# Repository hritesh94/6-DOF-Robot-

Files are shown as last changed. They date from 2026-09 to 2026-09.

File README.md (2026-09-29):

# TW2KA 6-DOF Robot Arm — custom PCB, firmware and browser controller 
# Instagram-https://www.instagram.com/zerobudgetbuilds?stkn=Z2p6NzZ4MDZwZGZy&utm_source=ig_contact_invite
# Youtube-https://youtube.com/@zerobudgetbuilds-e4w?si=uFIiYkhq8qUiVjJG

WhatsApp Image 2026-09-28 at 2 36 28 PM


## Here if you see closely the tx and rx connection to the Teensy board is wrong it should be flipped i will correct and upload it in the next iteration
pcb

A 3D-printed 6-axis robot arm that homes itself, moves in joint or Cartesian space using inverse kinematics, and **draws** from G-code, SVG files or photos.

> 📹 

https://github.com/user-attachments/assets/a5f0eb35-01ec-4ff1-84e9-ad130a259d0c

## Final Result of What the Robot drew
WhatsApp Image 2026-09-27 at 4 41 34 PM

| | |
|---|---|
| **Mechanics** | Open-source [TW2KA](https://youtube.com/@tw2ka644) arm, 3D-printed on my own printer, assembled and modified |
| **Electronics** | Custom PCB (KiCad): Teensy 4.1 + 6× TMC2209 stepper drivers + 5 endstops |
| **Firmware** | Arduino/Teensyduino, AccelStepper, coordinated moves, homing, EEPROM calibration |
| **Controller** | Single HTML file: live 3D model (three.js), jogging, Cartesian IK, G-code drawing, image → G-code |
| **Status** | Version 1: working and drawing |

---

## What it can do

- **Jog** each joint (press and hold) and **home** J1–J5 on their endstops
- **Cartesian control**: move the tool in X/Y/Z/roll/pitch/yaw, or position-only with the wrist held still
- **Live 3D model** showing the commanded pose and the real motor position side by side
- **Calibrate from the app**: motor direction, homing direction, zero offset, soft limits and steps/degree per joint, all saved on the Teensy
- **Draw**: run G-code (G0/G1/G2/G3, M3/M5), find the reachable drawing area, fit drawings to it, and convert SVG / PNG / JPG images into G-code (outline or hatch)
- **Safety**: E-stop, endstop protection during moves, per-joint speed caps, table-height limit, wrist-flip blocking

## Repository layout

```
6-DOF-Robot-/
├── README.md                          ← you are here
├── LICENSE
├── app/
│   ├── README.md                      ← what the controller does, how to use it
│   ├── tw2k_controller.html           ← the whole controller (open in Chrome/Edge)
│   └── images/                        ← screenshots of the app
├── firmware/
│   └── tw2k_firmware/
│       └── tw2k_firmware.ino          ← Teensy 4.1 firmware
├── hardware/
│   ├── BOM.md                         ← motors, drives, electronics
│   ├── cad/
│   │   ├── README.md                  ← my parts and changes explained
│   │   ├── pen_holder.3mf             ← my pen holder (print-ready)
│   │   ├── pen_holder_preview.png
│   │   ├── Baseplate-v2.3mf           ← modified TW2KA baseplate (inner circle +2 mm)
│   │   ├── baseplate_v2_preview.png
│   │   ├── base_stand_gear_with_lip.3mf  ← modified TW2KA base gear (added lip)
│   │   ├── base_stand_gear_preview.png
│   │   └── Arduino robot arm files + step/   ← original TW2KA design files (credit: TW2KA)
│   │       ├── README.md
│   │       ├── Arm1/  Arm2/  Base/    ← printable parts
│   │       ├── Assembly step.STEP     ← full 3D assembly
│   │       ├── Hardware.txt           ← original hardware list
│   │       └── coupler stl file for planetary geared nema motor.3mf
│   └── pcb/
│       ├── README.md
│       ├── tw2ka_pcb.kicad_pro        ← open this in KiCad
│       ├── tw2ka_pcb.kicad_sch        ← schematic
│       ├── tw2ka_pcb.kicad_pcb        ← 4-layer board layout
│       ├── fp-lib-table
│       ├── 3d/
│       │   └── tw2ka_pcb.step         ← 3D model of the board
│       └── fabrication/               ← drill files (+ Gerbers)
├── docs/
│   ├── 01-build-log.md                ← the story: what I tried, what failed, why each feature exists
│   ├── 02-hardware.md                 ← PCB, pin map, drivers, motors
│   ├── 03-kinematics.md               ← DH parameters, workspace, how the IK works
│   ├── 04-firmware.md                 ← serial protocol, config, EEPROM
│   ├── 05-controller-app.md           ← code map of the HTML app, how to add features
│   ├── 06-calibration.md              ← first-time setup, step by step
│   ├── 07-drawing.md                  ← G-code and image drawing
│   ├── 08-troubleshooting.md          ← problems I hit and how I fixed them
│   └── roadmap.md                     ← ROS 2, MoveIt, camera, learning plans
└── media/                             ← photos and videos
```

## Quick start

1. **Flash the firmware**: open `firmware/tw2k_firmware/tw2k_firmware.ino` in the Arduino IDE with Teensyduino, board **Teensy 4.1**, USB type **Serial**, install **AccelStepper**, upload.
2. **Open the app**: double-click `app/tw2k_controller.html` in **Chrome or Edge** on a computer (Web Serial is needed; phones run it as a simulator only).
3. **Connect → Enable all → Home all.**
4. Follow [docs/06-calibration.md](docs/06-calibration.md) once, then try Cartesian mode and drawing.

⚠️ Keep a hand near STOP (or press **Esc**) and your motor power switch, especially the first time.

## The story in short

1. My first arm used servo motors; I wanted something **precise**.
2. Builders like **Aaed Musa** and **Michael Reeves** inspired me, but precise arms often use BLDC motors with FOC drivers, far over my ₹10–20k budget.
3. **[Skyentific](https://youtube.com/@skyentific)** showed me a precise arm can use **stepper motors**, but his belts aren't sold in India.
4. I found **[TW2KA](https://youtube.com/@tw2ka644)**, and **[Matt.xyz++](https://youtube.com/@matt-04)** showed the same arm writing with G-code (and mentioned TMC drivers). I bought a 3D printer and printed every TW2KA part.
5. TW2KA uses an Arduino Mega + RAMPS + A4988. I moved to a **Teensy 4.1 + TMC2209s**. On a perfboard I killed two drivers and a motor (lesson: never unplug a motor while powered), so I learned **KiCad** and designed my own PCB.
6. Software: the **TW2KA GUI** only jogged the joints, and **Chris Annin's AR4 app** didn't move my arm correctly in X even with my DH parameters. So I **made my own app**.
7. Debugging on the real arm: J3 turning the wrong way, J5's steps per degree, wrist flips, J2 wiring. Then it drew its first SVG.

Full version: [docs/01-build-log.md](docs/01-build-log.md).

## How this was built (honest credits)

- **Mechanical design**: the open-source **TW2KA** arm ([YouTube](https://youtube.com/@tw2ka644)). I printed all parts on my own 3D printer, assembled the arm and modified parts in Fusion 360 (2–3 iterations, plus my own pen holder).
- **PCB**: designed by me in KiCad, soldered and brought up by me (after an earlier perfboard version).
- **Kinematics measurements**: I measured the link geometry axis-to-axis in Fusion 360; the DH table came from those measurements.
- **Software**: the firmware, inverse kinematics and controller app were written with **Claude (Anthropic)** as an AI coding partner, from my requirements, and then tested, debugged and calibrated by me on the real robot.
- **Inspiration and learning**:
  - [Skyentific](https://youtube.com/@skyentific) (stepper-driven 6-axis arm)
  - [Matt.xyz++](https://youtube.com/@matt-04) (TW2KA arm drawing with G-code, TMC drivers)
  - Chris Annin's **AR4** robot and software
  - **Aaed Musa** and **Michael Reeves** (robot builders who got me started)
  - **DIY Engineers** and **Electronoobs** on YouTube (how TMC stepper drivers work)
  - [Inverse kinematics basics playlist](https://www.youtube.com/watch?v=MYJIEiz2DKg&list=PLY6RHB0yqJVasji1rwZAGYirD8zW1ipj-)
- **Libraries**: [AccelStepper](https://www.airspayce.com/mikem/arduino/AccelStepper/) by Mike McCauley, [three.js](https://threejs.org/).

## License

The firmware and app in this repository are released under the MIT License (see `LICENSE`). The TW2KA mechanical design belongs to its creator; check their license before redistributing any of their CAD files.

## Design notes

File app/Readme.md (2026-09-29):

# TW2KA Arm Controller (web app)

A complete controller for the 6-axis arm in **one HTML file**. Open it in your browser, plug in the Teensy over USB, and you can jog, home, calibrate, move in X/Y/Z with inverse kinematics, and draw from G-code or images, while a live 3D model shows exactly what the arm is doing.



## Requirements

- **Chrome or Edge on a computer.** The app talks to the Teensy with the Web Serial API, which these browsers support.
- The arm's firmware flashed on the Teensy 4.1: [`firmware/tw2k_firmware/tw2k_firmware.ino`](../firmware/tw2k_firmware/tw2k_firmware.ino)
- Nothing to install. On a phone, or without the Teensy, it runs as a **simulator**.

## Quick start

1. Download `tw2k_controller.html` and double-click it (it opens in your browser).
2. Click **Connect Teensy** and pick the Teensy's port.
3. Press **Enable all**, then **Home all**.
4. Jog with **−/+** or drag the sliders. The 3D model follows the real arm.

⚠️ Keep a hand near **STOP** (or press **Esc**) and the motor power switch, especially the first time.

## Features

### Live 3D view
- **Solid arm** = where you're telling it to go. **Faint arm** = where the motors really are.
- Drag to rotate, scroll or pinch to zoom.
- Built from the arm's real DH parameters, so what you see matches the geometry.

### Joint control
- A slider per joint to go to an exact angle.
- **Press and hold − / +** to jog a joint, like a classic robot GUI.
- **Current pose** readout: tool X/Y/Z, roll/pitch/yaw, and all six joint angles.



### Cartesian control (inverse kinematics)


- Move the tool in **X, Y, Z** and set **roll, pitch, yaw**; the app solves all six joint angles.
- **Hold tool angle** mode (uses all 6 joints) or **Position only** mode (J1–J3 move, the wrist stays still).
- Blocks sudden **wrist flips**, respects joint limits, and has a **table-height limit** so the tool never goes into the table.

### Motors
- **Motor enable**: turn each joint's motor on or off.
- **Motor direction**: reverse a joint whose real motion is opposite to the 3D model.
- **Hardware test**: pulse a motor 1600 steps forward and back to check wiring.


### Homing and calibration


- **Home all** or one joint at a time, with live endstop indicators.
- Set each joint's **homing direction**, **zero position** (*zero here*), **soft limits** (*min/max here*, *endstop only*) and **steps per degree** (*fix from measurement*).
- Everything is saved on the Teensy, so it's remembered after a power-cycle.

### Drawing


- Run **G-code** (G0/G1/G2/G3, M3/M5) with straight-line motion and pause / resume / stop.
- **Find drawing area**: shows the largest area the pen can reach (yellow box in 3D).
- **Fit G-code to area**, and **Image → G-code** for SVG, PNG and JPG (outline or hatch fill).
- **Check path** tests every point first and tells you the exact line that can't be reached.

## How it's built

- Plain HTML, CSS and JavaScript in a single file, with [three.js](https://threejs.org/) (r128) for 3D.
- Forward kinematics from the DH table; inverse kinematics with a damped-least-squares solver.
- Talks to the firmware with simple text commands like `M j1 … j6`, `H`, `J n +1`. The full list is in [docs/04-firmware.md](../docs/04-firmware.md).
- Code map and how to add features: [docs/05-controller-app.md](../docs/05-controller-app.md).

Built with **Claude (Anthropic)** as an AI coding partner, from my requirements, and tested and calibrated on the real arm.

## More docs

- First-time setup: [docs/06-calibration.md](../docs/06-calibration.md)
- Drawing guide: [docs/07-drawing.md](../docs/07-drawing.md)
- Troubleshooting: [docs/08-troubleshooting.md](../docs/08-troubleshooting.md)

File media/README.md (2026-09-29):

# Media

Suggested shots (add them and link from the README and docs):

- `drawing.mp4` / `drawing.gif` — the arm drawing (the most important one)
- `pcb_render.png`, `pcb_soldered.jpg`
- `assembly_*.jpg` — build progress
- `app_3d_view.png` — controller with the 3D model
- `reachable_area.png` — yellow drawing-area box
- `first_drawing.jpg`

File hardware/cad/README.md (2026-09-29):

# CAD

The arm is the open-source **TW2KA** design ([TW2KA on YouTube](https://youtube.com/@tw2ka644)); get the original parts from there.

This folder contains only **my own and modified parts**.

## Pen holder

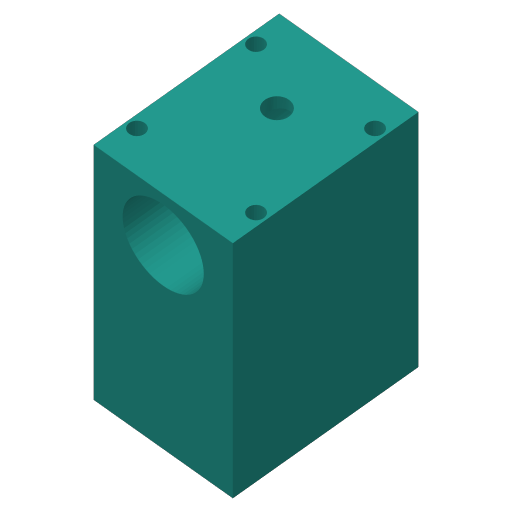
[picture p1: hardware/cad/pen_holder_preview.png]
Pen holder


| | |
|---|---|
| File | [`pen_holder.3mf`](pen_holder.3mf) (print-ready project, opens in Bambu Studio / OrcaSlicer / PrusaSlicer) |
| Size | about 24 × 18 × 33 mm |
| Design | block with four mounting holes plus a centre hole on top (to the J6 flange) and a side bore that holds the pen |
| Why | lets the arm hold a pen for G-code drawing |

After mounting a pen, measure how far the **pen tip is below the flange** and **ahead of it**, and enter both in the controller's G-code drawing card (see [docs/07-drawing.md](../../docs/07-drawing.md)).

## Baseplate v2 (modified TW2KA part)

baseplate_v2_preview

| | |
|---|---|
| File | [`Baseplate-v2.3mf`](Baseplate-v2.3mf) (print-ready project) |
| Size | about 167 × 80 × 12 mm |
| Original | TW2KA baseplate (see [Arduino robot arm files + step](Arduino%20robot%20arm%20files%20+%20step/)) |
| Change | the large inner circle was cut **2 mm** larger |
| Why | [describe what it fixed, e.g. the bearing / shaft now fits without rubbing, and the base turns more smoothly] |

## Base stand gear with lip (modified TW2KA part)

base_stand_gear_preview

| | |
|---|---|
| File | [`base_stand_gear_with_lip.3mf`](base_stand_gear_with_lip.3mf) (print-ready project) |
| Size | about 70 mm across (95 mm including the side arm), 9.3 mm thick |
| Original | TW2KA base stand gear (see [Arduino robot arm files + step](Arduino%20robot%20arm%20files%20+%20step/)) |
| Change | added a **lip** (flange) around the bottom of the toothed pulley |
| Why | [describe what it fixed, e.g. keeps the J1 belt from slipping off the pulley] |

## Other modified parts

- [ ] Parts from my 2–3 Fusion 360 iterations: list each one with what changed and why

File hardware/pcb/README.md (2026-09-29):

# Control PCB (KiCad)

My own control board for the TW2KA arm: a **Teensy 4.1** driving **six TMC2209** stepper drivers, with endstop inputs. Designed in **KiCad 10**.

| | |
|---|---|
| Size | 102 × 100 mm |
| Layers | 4 (F.Cu, In1.Cu, In2.Cu, B.Cu) |
| MCU | Teensy 4.1 (socketed) |
| Drivers | 6 × TMC2209 modules (socketed) |
| Per driver | STEP, DIR, EN to the Teensy; UART RX/TX lines routed (J1–J6_RX/TX); MS1, MS2 and SPREAD selectable |
| Endstops | 5 inputs (SW_1–SW_5) for J1–J5 |
| Power | Motor supply via terminal block and fuse, 100 µF capacitor per driver, separate logic supply (VIO) |
WhatsApp Image 2026-09-28 at 1 49 23 PM
pcb

https://github.com/user-attachments/assets/b51a67fe-33f5-430a-8fab-c27dd11908fc

Pin map and endstop wiring: [docs/02-hardware.md](../../docs/02-hardware.md).

## Files

```
hardware/pcb/
├── tw2ka_pcb.kicad_pro     ← open this in KiCad
├── tw2ka_pcb.kicad_sch     ← schematic
├── tw2ka_pcb.kicad_pcb     ← board layout
├── fp-lib-table            ← project footprint library table
├── Tmc2209_pin_socket.pretty/  ← custom TMC2209 socket footprint (to add)
├── 3d/
│   └── tw2ka_pcb.step      ← 3D model of the assembled board
└── fabrication/
    ├── tw2ka_pcb-PTH.drl   ← plated drill file
    ├── tw2ka_pcb-NPTH.drl  ← non-plated drill file
    └── gerbers/            ← Gerber files for the board house (to add)
```

Opening the board works without the footprint libraries (footprints are stored inside the `.kicad_pcb`). To **edit** footprints you also need the `Tmc2209_pin_socket.pretty` folder and the Teensy footprint library (`teensy.pretty`, available on GitHub).

## Ordering the board

Upload the Gerbers and both drill files from `fabrication/` to a PCB manufacturer (JLCPCB, PCBWay, etc.) and choose **4 layers**.

## Lessons from the perfboard version

- Put a 100 µF capacitor rated **35 V** (not 25 V) on each driver's motor supply.
- **Never plug or unplug a motor while the driver is powered.** It can destroy a TMC2209, which is how I lost two drivers and a motor.

## Next revision

- [ ] [Describe the small tweak you want to make]

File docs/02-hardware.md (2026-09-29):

# Hardware

> 📷 Suggested: PCB 3D render from KiCad, soldered board, board installed in the base, wiring overview.

## Control board

- **MCU**: Teensy 4.1 (3.3 V logic, **not 5 V tolerant**)
- **Drivers**: 6× TMC2209 modules in standalone STEP/DIR mode
- **Endstops**: 5 sockets (J7–J11 on the board) for J1–J5; J6 has no switch
- **Design files**: `hardware/pcb/` (KiCad project, schematic PDF, Gerbers)

### Pin map (Teensy 4.1)

| Joint | STEP | DIR | EN (active LOW) | Endstop pin | Board socket |
|---|---|---|---|---|---|
| J1 | 3 | 2 | 4 | 32 | J7 |
| J2 | 6 | 5 | 9 | 31 | J8 |
| J3 | 12 | 11 | 26 | 30 | J9 |
| J4 | 23 | 22 | 19 | 29 | J10 |
| J5 | 15 | 14 | 13 | 28 | J11 |
| J6 | 37 | 36 | 38 | (27 reserved, no switch) | — |

### Endstop wiring

Each socket: pin 1 = signal, pin 2 = GND. On the Omron switch, the **NC** contact goes to pin 1 and **COM** to pin 2; **NO** is left unconnected. The Teensy uses its internal pull-up, so:

- not pressed → LOW
- pressed → HIGH
- **broken wire → HIGH**, so a loose wire stops the arm instead of letting it crash (fail-safe)

### TMC2209 notes

- **Microstepping** is set by MS1/MS2 (standalone): GND/GND = 8, MS1 high = 32, MS2 high = 64, both high = 16. Most joints run at 8; my J5 driver is at 16.
- Set each driver's current with its **Vref** potentiometer *before* connecting motors; never plug/unplug a motor while powered.
- J2's motor is small (0.4 A), so its current and speed matter most.

## Motors and drives

| Joint | Motor | Drive | Reduction | Steps/° |
|---|---|---|---|---|
| J1 | 17HS4401S | 100T / 16T belt | 6.25 | 27.778 |
| J2 | 17HS13-0404S-PG5 | 5.18:1 planetary × 80T / 16T belt | 25.9 | 115.111 |
| J3 | 17HS15-1504S1 | 100T / 16T belt | 6.25 | 27.778 |
| J4 | Casun 36SHD4001-11B | 60T / 16T belt | 3.75 | 16.667 |
| J5 | Casun 35SHD4310-12 | 32T / 16T belt | 2 | 17.778 (driver at 16 microsteps) |
| J6 | Casun 20SHD0003-20 | 32T / 16T belt | 2 | 8.889 |

Steps/° = 200 × microsteps × reduction ÷ 360.

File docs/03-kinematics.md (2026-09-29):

# Kinematics

## Measurements (Fusion 360, axis-to-axis, mm)

| Pair | Distance | Angle | Notes |
|---|---|---|---|
| Base face → J2 | 135.30 | — | Perpendicular from the mounting face |
| J1 ↔ J2 | 37.50 | 90° | Shoulder offset |
| J2 ↔ J3 | 160.00 | 0° | Upper arm, parallel axes |
| J3 ↔ J4 | 15.00 | 90° | Elbow offset |
| J3 ↔ J5 | 139.21 | 0° | Elbow to wrist centre (diagonal) |
| J4 ↔ J5, J5 ↔ J6 | 0 | 90° | Intersecting → **spherical wrist** |

The 139.21 mm diagonal splits into a 15 mm offset and a 138.40 mm forearm: √(139.21² − 15²) = 138.40.

## DH table (standard convention)

| i | a (mm) | α | d (mm) | θ |
|---|---|---|---|---|
| 1 | 37.5 | −90° | 135.3 | θ1 |
| 2 | 160 | 0° | 0 | θ2 − 90° |
| 3 | 15 | −90° | 0 | θ3 |
| 4 | 0 | +90° | 138.4 | θ4 |
| 5 | 0 | −90° | 0 | θ5 |
| 6 | 0 | 0° | 48 | θ6 |

d6 = 48 mm is wrist centre to tool flange (measured 47–50 mm). A pen's own offset is set separately in the drawing card.

### Zero pose

All joints at 0° means: upper arm vertical, forearm horizontal pointing +X, wrist straight, flange facing +X. Calibration makes the real arm match this pose (see [06-calibration.md](06-calibration.md)).

## Forward kinematics

Each joint contributes one DH transform; multiplying them gives the flange pose:

```
T0_6 = A1(θ1) · A2(θ2) · A3(θ3) · A4(θ4) · A5(θ5) · A6(θ6)
```

## Inverse kinematics (how the app does it)

The app uses a **numerical** solver (damped least squares) rather than closed-form equations:

1. Start from the arm's current joint angles.
2. Compute the flange pose with FK and the error to the target (position in mm, orientation in radians).
3. Build the 6×6 Jacobian from the joint axes and positions.
4. Take a small damped step `Δq = Jᵀ (J Jᵀ + λ² I)⁻¹ e`, clamp to joint limits, repeat until the error is under 0.01 mm.

Why numerical: it works with **any** DH table, so it kept working while signs and offsets were being corrected, and starting from the current pose picks the solution closest to where the arm already is.

Extra rules added from real-world testing:
- **Wrist-flip blocking**: a step that would swing any joint more than 25° at once is refused. Near J5 = 0 the wrist has two equivalent solutions (J4±180°, −J5, J6±180°); the flip is fine on paper but dangerous on the real arm.
- **Position-only mode**: solves X/Y/Z with J1–J3 only and keeps J4–J6 fixed.
- **Locked joints**: disabled motors are excluded from the solve.
- **Table limit**: solutions that put the flange, elbow or wrist below the table are rejected.

### Closed-form alternative (to do myself)

Because the wrist is spherical, the IK can also be solved analytically: find the wrist centre, solve J1 with atan2, solve J2/J3 as a 2-link planar problem with the law of cosines, then solve J4–J6 from the remaining rotation. Coding this myself is on the [roadmap](roadmap.md).

## Workspace (approximate)

- Max horizontal reach from the J1 axis: 37.5 + 160 + 139.21 ≈ 337 mm (+ tool)
- Max height above the base face: 135.3 + 160 + 139.21 ≈ 435 mm (+ tool)
- The drawing card's **Find drawing area** computes the real usable area for a given tool angle.

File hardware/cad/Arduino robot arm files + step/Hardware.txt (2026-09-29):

Steppers:

From www.omc-stepperonline.com models:
	17HS13-0404S-PG5 (Nema 17 with 5:1 planetary gearbox)
	14HR05-0504S (Round Nema 14 7Ncm)
	14HS08-0404S (Nema 14 5Ncm)
	17HS16-2004S1 (Nema 17 45Ncm)

From banggood.com:
	Nema 17 (https://www.banggood.com/42mm-12V-Nema-17-Two-Phase-Stepper-Motor-For-3D-Printer-p-1164619.html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)
	Nema 8 (https://www.banggood.com/JKM-NEMA8-1_820-Hybrid-Stepper-Motor-Two-Phase-30mm-Motor-For-CNC-Mill-Router-p-980604.html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)

Limit switches:
	https://www.banggood.com/10Pcs-Micro-Limit-Switch-Roller-Lever-5A-125V-Open-Close-Switch-p-945733.html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

Pulleys and belts:
	GT2 16tooth (4pcs)
	GT2 16tooth timing pulley without tooth (2pcs)
	GT2 6mm closed loop belts (280mm 2pcs, 200mm 1pcs, 158mm 1pcs)
	HTD3 16T pulley
	HTD3 closed belt 330mm

Bearings:
	608 8x22x7 (2pcs)
	625 5x16x5 (4pcs)
	6002 15x32x9 (4pcs)
	20X35X10 axial ball bearing (1pcs, originally used 2 but only needs one between stand and base)

Bunch of nuts and bolts mainly m3 and m4 hex head (M8 bolts on the stand, base (for HTD3 tensioner bearings) and Arm2 mount)

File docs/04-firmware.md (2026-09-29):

# Firmware (Teensy 4.1)

File: `firmware/tw2k_firmware/tw2k_firmware.ino` — needs **Teensyduino** and the **AccelStepper** library.

## What it does

- Drives 6 steppers with **coordinated moves**: all joints start and finish together, each with its own speed cap.
- **Homes** J1–J5: fast approach to the switch, back off, slow second touch, then sets that angle.
- **Stops everything** if an endstop is hit while moving toward it.
- **Saves calibration in EEPROM**: motor direction, homing direction, zero offsets, soft limits, steps/degree.

## Config at the top of the file

| Setting | Meaning |
|---|---|
| `STEP_PIN`, `DIR_PIN`, `EN_PIN`, `SW_PIN` | Pin map (matches my PCB) |
| `MICROSTEPS`, `GEAR` | Default steps/degree (can be overridden from the app) |
| `INVERT` | Default motor directions |
| `LIM_MIN`, `LIM_MAX` | Default soft limits (degrees) |
| `HOME_DIR`, `OLD_RETURN_STEPS`, `HOME_FAST`, `HOME_SLOW`, `SEARCH_MAX` | Homing |
| `MAX_DEG_S` | Top speed per joint (J2 capped at 12°/s) |
| `JOG_DEG`, `JOG_ACC_DEG` | Jog speed and ramp |

## Serial protocol

USB serial, one command per line.

| Command | Action |
|---|---|
| `M j1 … j6` | Move to joint angles (degrees, absolute, coordinated) |
| `V deg/s` | Set max joint speed |
| `J n ±1` / `J 0 0` | Start / stop hold-to-jog on joint n |
| `H` / `H n` | Home J1–J5 (then go to zero) / home joint n |
| `Z` | Make the current position zero on all joints (saved for homed joints) |
| `O n` | Make joint n's current position its zero (saved) |
| `K n min max` | Set joint n's soft limits (saved) |
| `G n spd` | Set joint n's steps/degree (saved) |
| `I n 0/1` | Normal / reversed motor direction (saved) |
| `D n ±1` | Direction joint n drives to find its switch (saved) |
| `N n 0/1` | Disable / enable joint n's driver |
| `S` / `E` / `R` | Smooth stop / E-stop (disable drivers) / re-enable |
| `T n` | Hardware test: raw 1600 steps forward and back |
| `X` | Forget all saved calibration (then power-cycle) |
| `?` | Report everything |

Replies: `P` positions, `L` endstops, `N` enables, `D` homing directions, `INV` motor directions, `SPD` steps/degree, `LIM` limits, plus `OK …`, `ERR …`, `HOMED`.

## EEPROM layout

| Address | Content |
|---|---|
| 0 | Magic byte (`0xB8`) |
| 1–5 | Homing direction per joint (+1 stored as 2, −1 as 0) |
| 6–11 | Motor reversed flags |
| 15 | Calibration magic (`0xC2`) |
| 16+ | `struct Cal { float lmin[6], lmax[6], off[6], spd[6]; }` |

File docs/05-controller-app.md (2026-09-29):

# Controller app

File: `app/tw2k_controller.html` — one self-contained HTML file (HTML + CSS + JavaScript). It loads **three.js r128** from a CDN and talks to the Teensy with the **Web Serial API**, so it needs **Chrome or Edge** on a computer. On a phone it runs as a simulator.

## Code map

The script is divided by banner comments (`// ===================== NAME =====================`). Search for these to jump around:

| Section | What's inside |
|---|---|
| **CONFIG + KINEMATICS** | `DH` table, `LIMITS`, `fkFrames()` forward kinematics, `ik()` damped-least-squares solver, `ikRobust()` |
| **APP STATE** | Current commanded joints `q`, reported joints `qActual`, mode, Cartesian target, rotation helpers, `poseOf()` |
| **UI BUILD** | Joint sliders, Cartesian sliders, nudge-step buttons, DH editor table |
| **IK in Cartesian mode** | `solveCart()`: solves from the current pose, blocks wrist flips, table limit, position-only mode |
| **3D VIEW** | three.js scene, arm drawing from DH frames (`drawArm()`), orbit/zoom controls |
| **REFRESH** | `refresh()`: redraws the arm and ghost, updates sliders and the pose readout |
| **SERIAL (Web Serial API)** | Connect/disconnect, `write()`, `readLoop()`, move streaming, STOP, speed |
| **PER-JOINT ENABLE + TEST** | Motor on/off buttons, direction reverse buttons, hardware test buttons |
| **HOMING / ENDSTOPS** | Homing buttons, homing direction, switch indicators, **Zero and limits** card, steps/degree fix, `handleLine()` parser for all replies |
| **HOLD-TO-JOG** | Press-and-hold jogging |
| **G-CODE DRAWING** | G-code parser, path builder, IK path check, 3D preview, runner, reachable-area finder, image → G-code (SVG tracing, outline, hatch) |

## Data flow

```
sliders / IK / G-code ──► q (commanded) ──► "M j1..j6" ──► Teensy
                                                              │
3D faint arm ◄── qActual ◄── "P j1..j6" (10 Hz while moving) ◄┘
```

## Adding a feature

1. **New firmware command**: add a branch in `handle()` in the firmware, and a reply line if the app needs state back.
2. **Parse the reply**: add a `line.startsWith('XYZ ')` case in `handleLine()`.
3. **UI**: add a `<section class="card">` in the HTML and wire its buttons in a new banner section.
4. **Kinematics changes**: only touch the **CONFIG + KINEMATICS** section; everything else uses `fkFrames()` / `ik()`.

## Notes

- The app keeps nothing in the browser between sessions; all calibration is saved on the Teensy.
- `LIMITS` in the app are overwritten by the Teensy's `LIM` report on connect.

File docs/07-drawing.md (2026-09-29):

# Drawing

> 📷 Suggested: the pen holder, the reachable-area box in the 3D view, a generated path preview, the finished drawing.

## Setup

1. Home the arm and pick a tool angle (mine: flange facing +X, pen pointing down).
2. Enter the pen offset: **pen tip below the flange** and **ahead of the flange** (mm).
3. Jog the pen tip onto the paper where the drawing should be and press **Set drawing origin here**.
4. Press **Find drawing area**. It flood-fills a 5 mm grid on the paper plane from the origin and keeps points the pen can reach on the paper and lifted, within joint limits, without wrist flips and above the table. The largest reachable rectangle appears as a yellow box.

## G-code

Supported: G0/G1, G2/G3 (I/J arcs), G90/G91, G20/G21, M3/M5.

- Pen **down** when Z ≤ 0 or after M3; **up** otherwise. Files with no Z and no M3/M5: G0 = travel, G1/G2/G3 = draw.
- **Fit G-code to area** scales and offsets any file into the reachable box.
- **Check path** splits every move into ≤ 2 mm steps, solves IK for all of them and reports the exact G-code line that can't be reached.
- **Run** sends one step at a time and waits for the Teensy to report arrival, so lines stay straight.

## Image → G-code

- **SVG**: every path, line, rect, circle, ellipse and polygon is sampled along its length (best for line art, logos and text).
- **PNG/JPG**: **Outline** traces dark regions with marching squares; **Hatch fill** fills them with horizontal lines. Adjust the darkness threshold.
- Strokes are simplified (Ramer–Douglas–Peucker, 0.15 mm), ordered nearest-first to reduce travel, sized to the reachable area, and checked automatically.

## Tips

- Start small (30–50 mm) near the origin.
- Hatch at 1.5–2 mm so lines don't merge.
- Accuracy depends on calibration: directions, zeros and steps/degree.

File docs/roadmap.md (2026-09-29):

# Roadmap

Version 1 works. Next, I want to understand and own every layer.

## Learning (next)

- [ ] Derive the closed-form IK for this arm on paper and code it myself in Python; compare with the app's numerical solver
- [ ] ROS 2: go beyond nodes and publishers/subscribers
- [ ] Write a **URDF** of the arm and view it in **RViz**
- [ ] Simulate it in **Gazebo**
- [ ] Plan motion with **MoveIt 2**
- [ ] A ROS 2 driver node that talks to this firmware over serial

## Robot improvements

- [ ] PCB revision (small fixes noted in `hardware/pcb/`)
- [ ] Continuous motion (look-ahead) instead of stop-and-go drawing steps
- [ ] Encoders or TMC2209 UART/StallGuard for stall detection
- [ ] Camera for vision-guided tasks (pick and place, drawing what it sees)
- [ ] Later: learning-based control / reinforcement learning experiments in simulation

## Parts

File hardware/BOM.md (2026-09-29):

# Bill of materials (main parts)

| Qty | Part | Notes |
|---|---|---|
| 1 | Teensy 4.1 | 3.3 V logic |
| 6 | TMC2209 stepper driver module | Standalone STEP/DIR; MS1/MS2 set microstepping |
| 1 | Custom control PCB | This repo, `hardware/pcb/` |
| 1 | 17HS4401S | J1 |
| 1 | 17HS13-0404S-PG5 (5.18:1 planetary) | J2 |
| 1 | 17HS15-1504S1 | J3 |
| 1 | Casun 36SHD4001-11B | J4 |
| 1 | Casun 35SHD4310-12 | J5 |
| 1 | Casun 20SHD0003-20 | J6 |
| 5 | Omron micro switch (NC wiring) | Endstops J1–J5 |
| — | GT2 belts and pulleys: 100T, 80T, 60T, 32T, 16T | See drive ratios in `docs/02-hardware.md` |
| 1 | Motor power supply (12–24 V) | + 100 µF capacitor near each driver |
| — | 3D-printed TW2KA parts, bearings, fasteners | See the original TW2KA project for its full list |

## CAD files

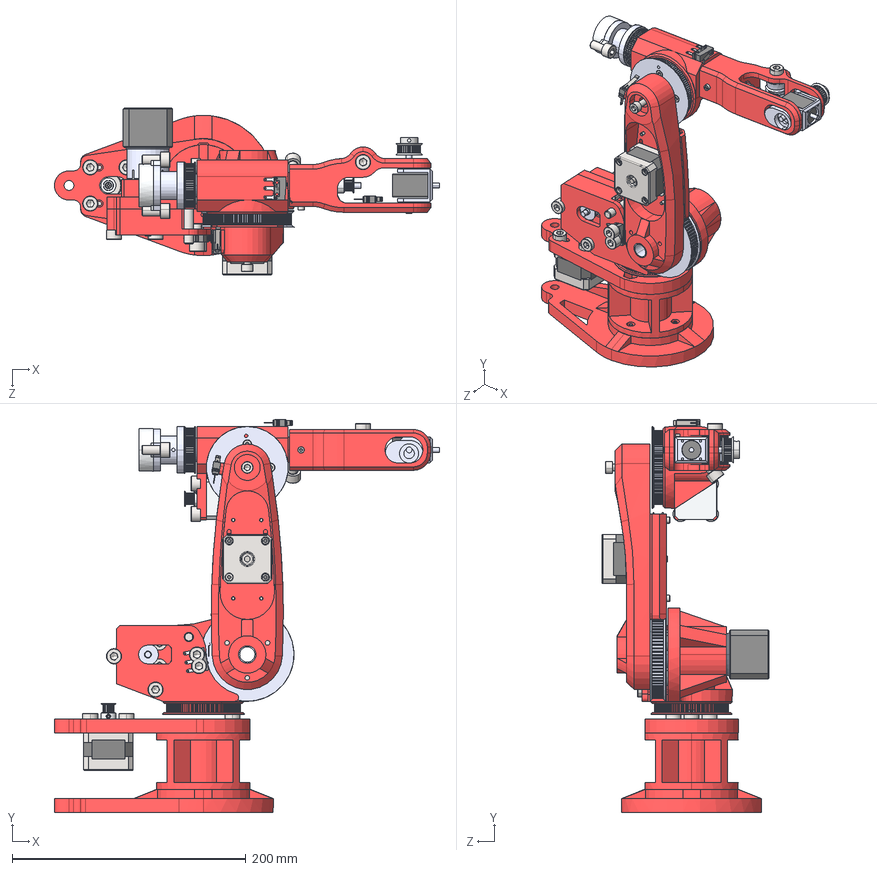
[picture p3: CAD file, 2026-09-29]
hardware/cad/Arduino robot arm files + step/Assembly step.STEP
329.3 x 336.5 x 142.9 mm
Arm1v2
socket head cap screw_iso_ISO 4762 M8 x 16 - 16N x 31
Base_Predeterminado x 2
Cuerpo_Predeterminado x 2
Tapa_Predeterminado x 2
Eje_Predeterminado x 2
GT2_16T_13x14_____________1 x 4
socket head cap screw_iso_ISO 4762 M6 x 12 - 12N
socket head cap screw_iso_ISO 4762 M3 x 25 - 18N x 4
Toothless pulley 16t gt2 x 2
Arm 2.3
HTD3M 80T
Arm 4.3
HTD80T 2mm spacer
90mm aluputki
Pulley100Tv5
100mm aluputki
Arm2Mountv2
Pulley60Tv2
15mm rikka 1.2mm
Nema 14 stepper
Nema 14 Round stepper
Motor 5 adapter
socket head cap screw_iso_ISO 4762 M4 x 16 - 16N x 4
limit-switch-bottomcase x 4
limit-switch-top-case x 4
pins x 4
switch_lever x 4
6mm akseli
socket head cap screw_iso_ISO 4762 M3 x 16 - 16N x 5
Rotation arm V3
GT2 hihna chamfer rulla x 2
Nema8 Stepperi (banggood.com)
Pulley32TGT2
bearing adapter J6 housing x 2
5mm akseli 2
5mm akseli 1
J6 kotelo
15mm 1.6 rikka
socket head cap screw_iso_ISO 4762 M8 x 40 - 28N
Pulley100TBase
socket head cap screw_iso_ISO 4762 M8 x 50 - 28N
Nema 17 planetary 5 to 1 gearbox
HTD pulley adapter
Motor1 spacer
Basewall cover v2
BaseWall_2_v2
3M HTD 16T 6mm Bore
Bottom spacer
Baseplate
Bottom Tube
Bottom support

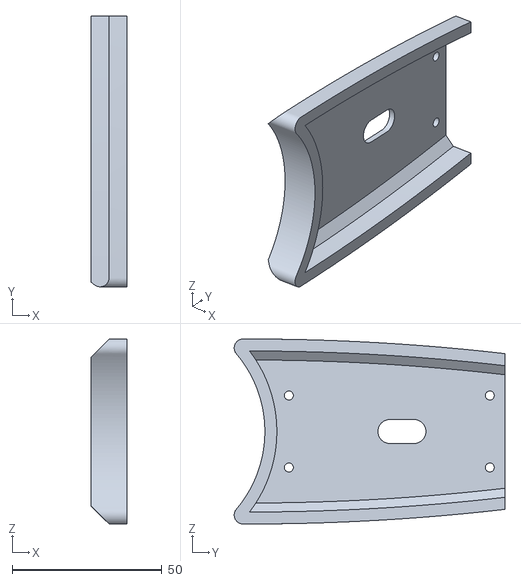
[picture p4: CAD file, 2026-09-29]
hardware/cad/Arduino robot arm files + step/Arm1/Arm 2.3.STL
12.0 x 90.2 x 61.7

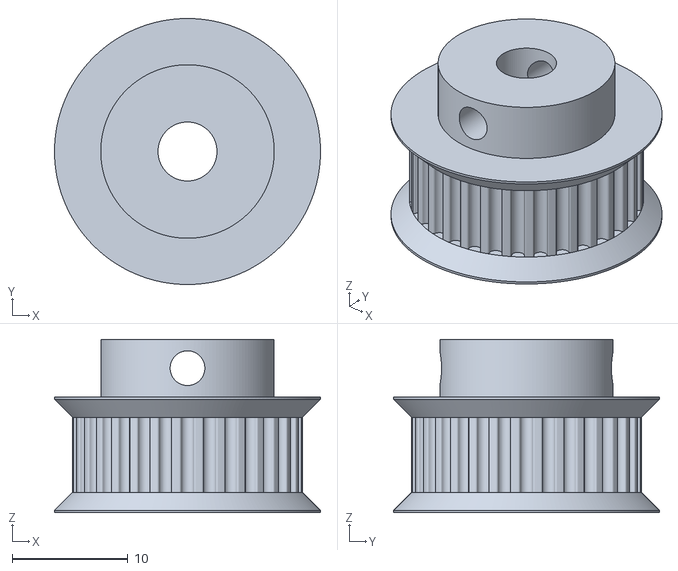
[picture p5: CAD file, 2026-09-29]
hardware/cad/Arduino robot arm files + step/Arm2/Pulley32TGT2.STL
23.0 x 23.0 x 15.0

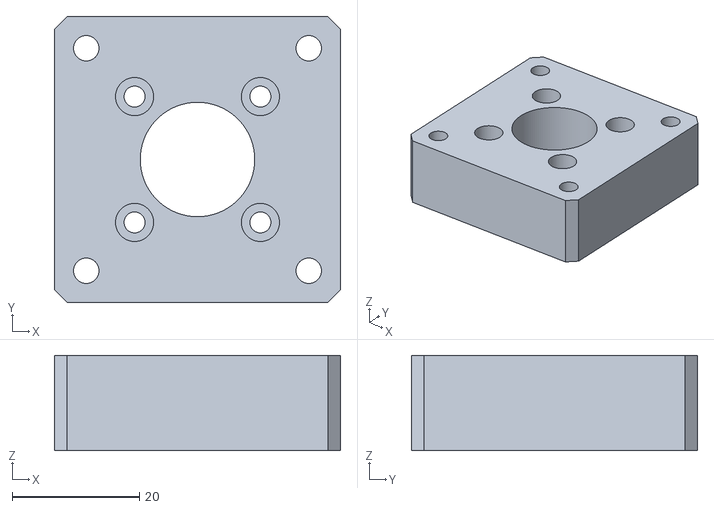
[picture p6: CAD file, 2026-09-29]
hardware/cad/Arduino robot arm files + step/Base/Motor1 spacer.STL
45.0 x 45.0 x 15.0

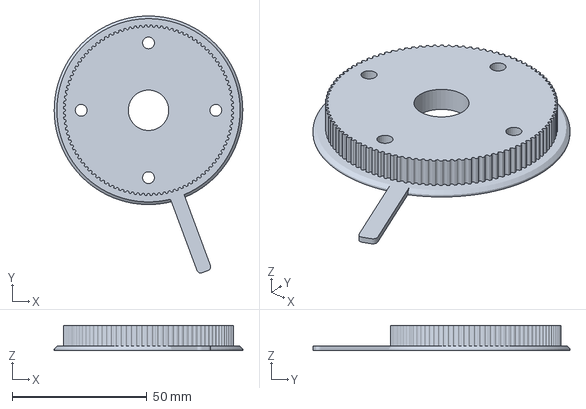
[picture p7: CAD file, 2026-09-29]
hardware/cad/base stand gear with lip.3mf
70.0 x 95.4 x 9.30 mm

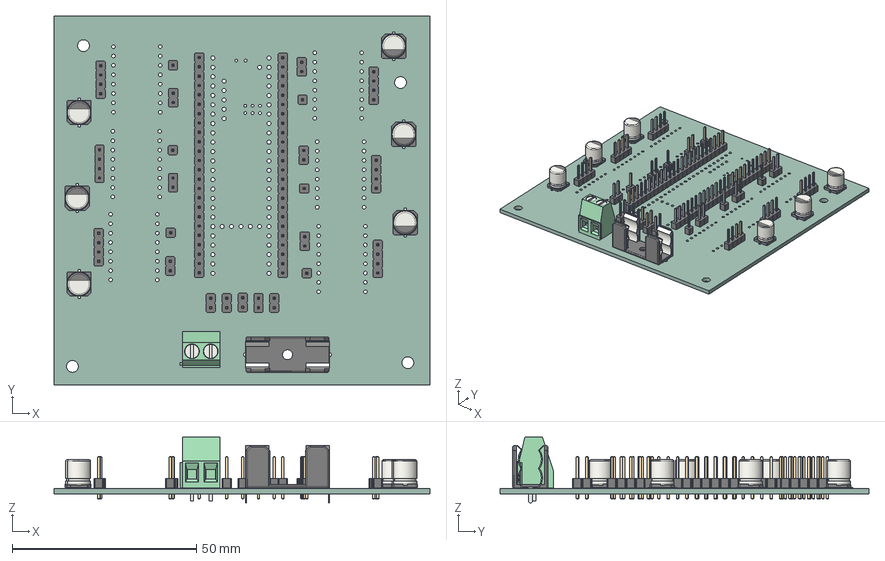
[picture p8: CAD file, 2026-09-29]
hardware/pcb/3d/tw2ka_pcb.step
102.0 x 100.0 x 17.8 mm
TerminalBlock_Phoenix_MKDS-1,5-2-5.08_1x02_P5.08mm_Horizontal
PinHeader_1x04_P254mm_Vertical x 6
PinHeader_1x01_P254mm_Vertical x 6
PinHeader_1x24_P254mm_Vertical x 2
A_Schurter_0031_8201
CP_Elec_63x77 x 6
PinHeader_1x02_P254mm_Vertical x 11
tw2ka pcb_PCB

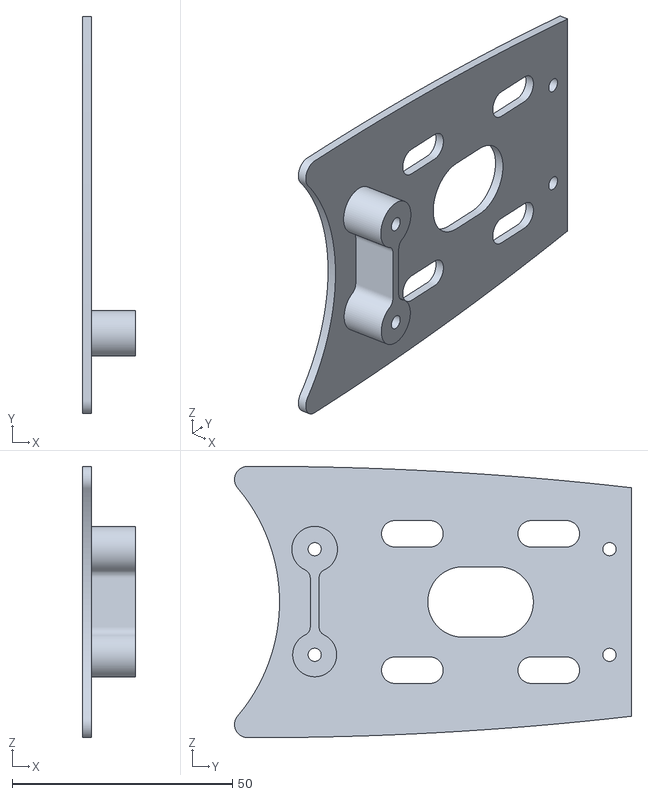
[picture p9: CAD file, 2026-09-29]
hardware/cad/Arduino robot arm files + step/Arm1/Arm 4.3.STL
12.0 x 90.2 x 61.7

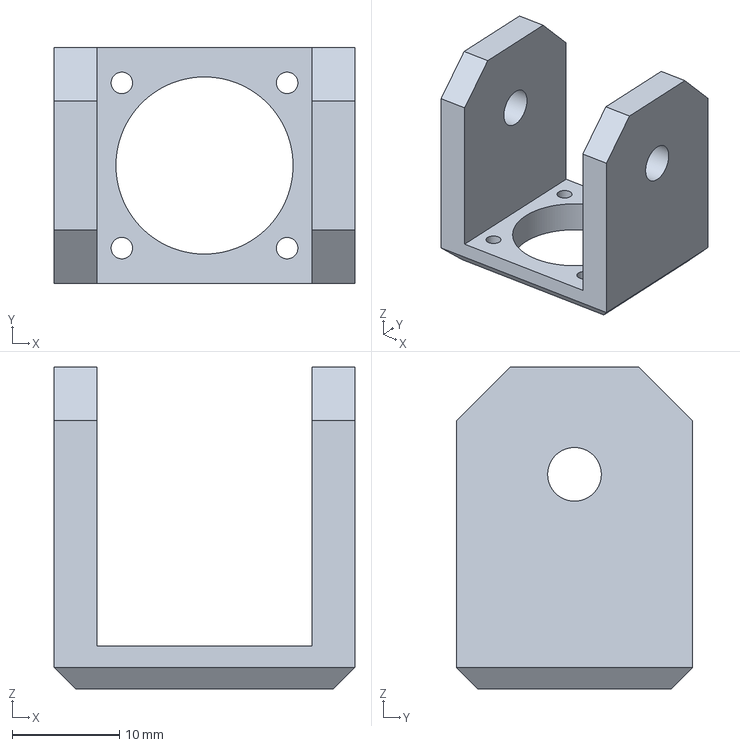
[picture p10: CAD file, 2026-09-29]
hardware/cad/Arduino robot arm files + step/Arm2/J6 housing.3mf
28.0 x 22.0 x 30.0 mm

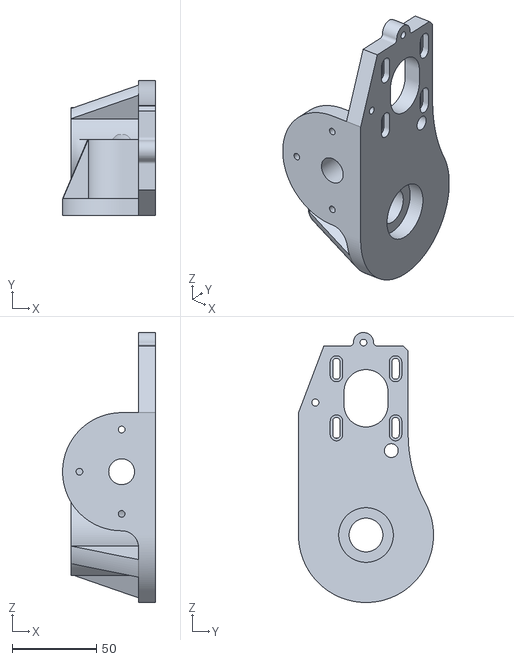
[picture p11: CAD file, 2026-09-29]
hardware/cad/Arduino robot arm files + step/Base/BaseWall_2_v2.STL
55.0 x 80.0 x 160.0

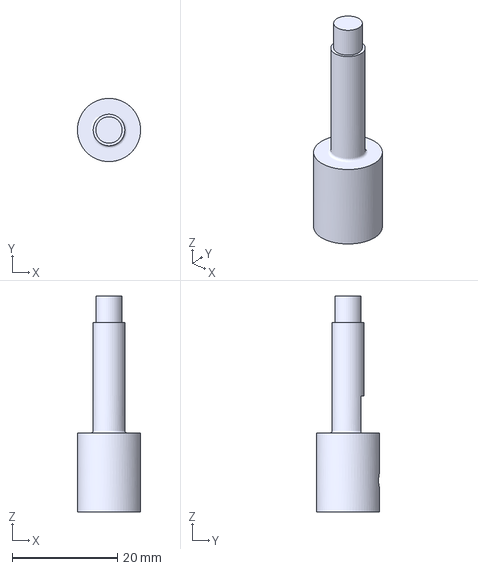
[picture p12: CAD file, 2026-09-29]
hardware/cad/Arduino robot arm files + step/coupler stl file for planetary geared nema motor.3mf
12.0 x 12.0 x 41.0 mm

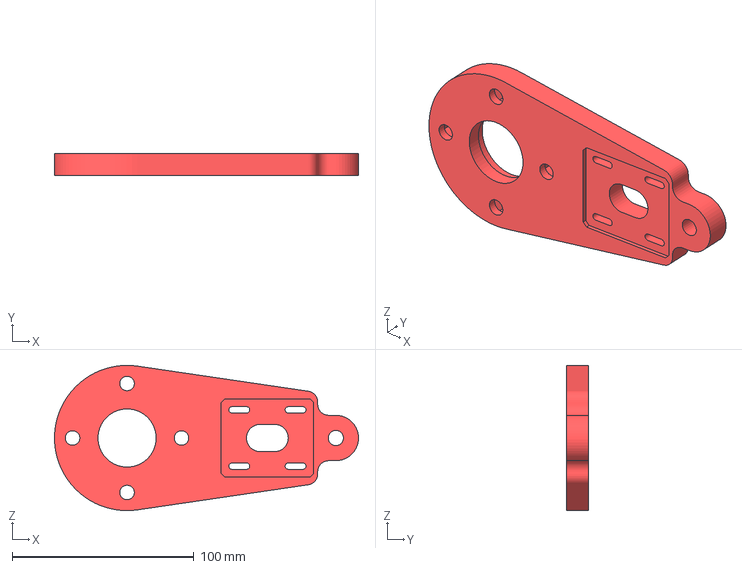
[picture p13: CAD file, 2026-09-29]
hardware/cad/Baseplate-v2.3mf
167.4 x 12.0 x 80.0 mm

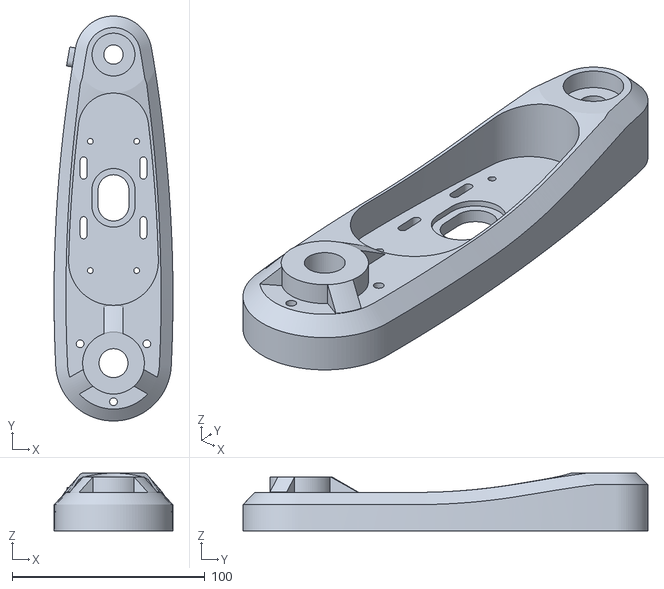
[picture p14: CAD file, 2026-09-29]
hardware/cad/Arduino robot arm files + step/Arm1/Arm1v2.STL
61.7 x 210.0 x 30.0

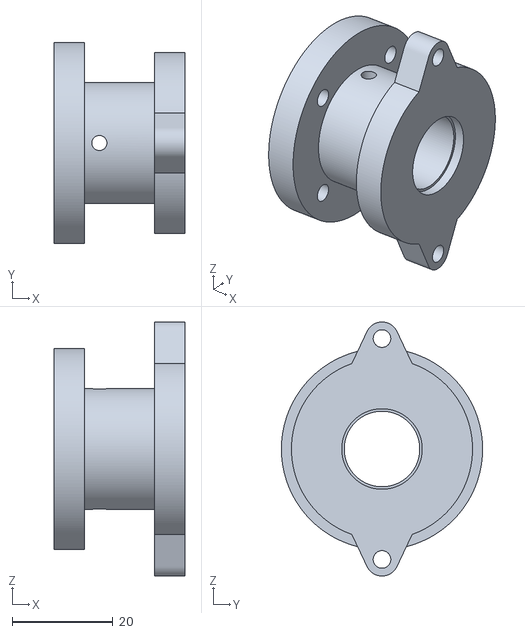
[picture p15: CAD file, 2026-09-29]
hardware/cad/Arduino robot arm files + step/Arm2/Motor 5 adapter.STL
26.0 x 40.0 x 50.5

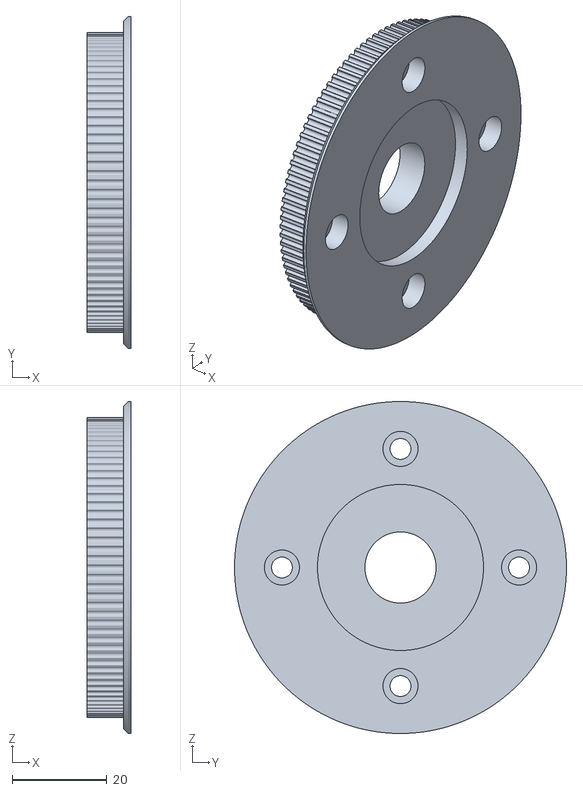
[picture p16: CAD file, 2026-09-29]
hardware/cad/Arduino robot arm files + step/Base/Pulley100TBase.STL
9.30 x 70.0 x 70.0

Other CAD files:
hardware/cad/pen_holder.3mf
hardware/cad/Arduino robot arm files + step/Arm1/HTD80T 2mm spacer.STL
hardware/cad/Arduino robot arm files + step/Arm2/Pulley100Tv5.STL
hardware/cad/Arduino robot arm files + step/Base/Basewall cover v2.STL
hardware/cad/Arduino robot arm files + step/Arm1/HTD3M 80T.STL
hardware/cad/Arduino robot arm files + step/Arm2/Arm2Mountv2.STL
hardware/cad/Arduino robot arm files + step/Arm2/GT2 belt chamfer roller.STL
hardware/cad/Arduino robot arm files + step/Arm2/J6 housing.STL
hardware/cad/Arduino robot arm files + step/Arm2/Pulley60Tv2.STL
hardware/cad/Arduino robot arm files + step/Arm2/Rotation arm V3.STL
hardware/cad/Arduino robot arm files + step/Arm2/bearing adapter J6 housing.STL

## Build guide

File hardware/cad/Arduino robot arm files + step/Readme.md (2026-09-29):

# Original TW2KA arm files

These are the **original design files of the TW2KA 6-axis robot arm**, made by the **TW2KA** YouTube channel. I printed my arm from these files.

- 📺 Build video: https://youtu.be/wI4Jh-T0Tlo
- 📺 Channel: https://youtube.com/@tw2ka644

> **All credit for this design goes to TW2KA.** I've included the files here so everything needed for this build is in one place. They're not my work, and they're shared as he published them. If you use them, please credit TW2KA and support his channel.




| File / folder | What it is |
|---|---|
| `Arm1/` | Parts for the first arm section |
| `Arm2/` | Parts for the second arm section |
| `Base/` | Parts for the base |
| `Assembly step.STEP` | Full 3D assembly of the arm (opens in Fusion 360, FreeCAD, SolidWorks, Onshape) |
| `Hardware.txt` | Hardware list from the original design (screws, bearings, belts, etc.) |
| `coupler stl file for planetary geared nema motor.3mf` | Coupler for the planetary-geared NEMA 17 motor (used on J2) |
| `Robot parts v1.PNG` | Overview of all printed parts |
| `Picture1.PNG`, `Picture2.PNG`, `Picture 3.PNG` | Reference pictures of the arm |

## How I used these files

1. Printed every part from `Arm1/`, `Arm2/` and `Base/` on my own 3D printer.
2. Bought the hardware listed in `Hardware.txt`, and the motors and belts listed in [BOM.md](../../BOM.md).
3. Assembled the arm using `Assembly step.STEP` and the pictures as a guide.

## What I changed

I kept TW2KA's mechanical design and changed only a few things:

- **Electronics:** instead of the original Arduino Mega + RAMPS + A4988 setup, I use my own PCB with a **Teensy 4.1 and six TMC2209** drivers (see [hardware/pcb](../../pcb/)).
- **Pen holder:** my own part for drawing, in [pen_holder.3mf](../pen_holder.3mf).
- **Small CAD tweaks:** 2–3 iterations in Fusion 360 so the arm runs better. These will be uploaded separately in [hardware/cad](../), so the original files here stay untouched.

For the full build story, see [docs/01-build-log.md](../../../docs/01-build-log.md).

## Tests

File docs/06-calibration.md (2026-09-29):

# First-time calibration

Do this once; everything is saved on the Teensy. Keep a hand near STOP (Esc) and the motor power switch.

## 1. Check the hardware

1. Connect, press **Enable all**.
2. Press each **test** button (J1–J6). Each motor should turn 1600 steps forward, then back.
   - Same direction twice → DIR wire problem.
   - Shuddering → a coil wire or connector problem.

## 2. Motor directions

Hold each joint's **+** button and compare the real arm with the 3D model:

- J2 + → upper arm tilts **forward**
- J3 + → forearm tilts **down**
- J4–J6 + → watch the coloured drum turn in the 3D view

If a real joint moves opposite to the model, tap its **Motor direction** button. (On my arm J3 and J5 needed reversing.)

## 3. Homing directions

Press **Home** on one joint at a time. If it drives away from its switch: **Stop homing**, jog to see which button moves it toward the switch, set **toward** to that button, and home again.

## 4. Steps per degree

Jog a joint about 90° in the app and measure the real movement. If they differ, press **fix from measurement** and enter both numbers, then re-home that joint. (My J5 was 2× off because its driver runs at 16 microsteps.)

## 5. Zeros

Home all, then for J3, J4 and J5: jog until the real arm matches the model's zero pose (forearm level, wrist square, flange straight and facing forward) and press **zero here**. Check with **Go to zero pose**.

## 6. Limits

For the switch side, press **endstop only**. For the other side, type a wider value, jog slowly to the physical end, back off a little and press **max here** / **min here**.

## 7. Table and tool

- Set **Lowest flange height above the table** (Cartesian tab) to your pen length plus a few mm.
- d6 (wrist centre → flange) is 48 mm in the DH table.

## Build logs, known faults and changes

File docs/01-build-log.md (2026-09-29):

# Build log — how this robot came together

This is the honest story of version 1: what I tried, what failed, and why each feature in the software exists. Every feature was added because the real robot needed it.

> 📷 Suggested photos for this page: printed parts laid out, half-assembled arm, the PCB before and after soldering, first homing, first drawing.

## 1. Why this robot

My first robot arm used **servo motors**. I didn't like it: I thought I couldn't learn inverse kinematics on it (I was wrong about that), and I wanted a **precise** robot.

I'd followed builders like **Aaed Musa** and **Michael Reeves** for a long time. Precise arms like theirs often use **BLDC motors with FOC control** (ODrive-style drivers), but they're expensive and every motor needs its own driver. My budget was **₹10–20k**, not ₹1 lakh.

Then **[Skyentific](https://youtube.com/@skyentific)**'s 6-axis arm showed me a precise arm can be built with **stepper motors**. But its belts aren't available in India, and getting them made would cost about ₹2,000 each.

I kept searching and found **[TW2KA](https://youtube.com/@tw2ka644)**. Its videos didn't show much of what it could do, so I was stuck between TW2KA and Skyentific, until **[Matt.xyz++](https://youtube.com/@matt-04)** showed the TW2KA arm **interpreting G-code and writing**. That decided it. He also mentioned using **TMC drivers** for better control.

## 2. Printing and assembling

I **bought a 3D printer** and printed every part TW2KA open-sourced, then assembled the arm with the motors and belt/planetary drives listed in [the BOM](../hardware/BOM.md). Along the way I made **2–3 CAD iterations in Fusion 360**, and later designed my own **pen holder**.

## 3. Electronics: the hard way

TW2KA uses an **Arduino Mega 2560 + RAMPS + A4988** drivers. That's good enough, but I wanted more precise control, so I raised my budget for a **Teensy 4.1** and **TMC2209** drivers. I learned how TMC drivers work from **DIY Engineers** and **Electronoobs** on YouTube, and by asking AI.

I first built the circuit on a **perfboard**, learning why each part is there: 100 µF capacitors on the motor supply, and why they should be rated 35 V (I first used 25 V ones from the local market at ~20–21 V, then switched to 35 V).

Then I made a mistake I didn't know about: **I unplugged a motor while the driver was powered**. That can destroy a TMC driver. I lost **two drivers and a motor**, and waited 1–2 months for replacements. Going back to the RAMPS board didn't work either, because it couldn't take more than about 15–16 V.

So I decided to learn it properly. I learned **KiCad**, designed my own PCB from what I'd learned about schematics, and waited about a month for it to be manufactured. I soldered it, ordered six new TMC2209s, and **every motor moved**. Details: [02-hardware.md](02-hardware.md).

## 4. Software: two apps that didn't work

- **TW2KA's own GUI and code**: I remapped the pins for my board (with AI help), but it could only **jog** the joints.
- **Chris Annin's AR4 app**: I found through a Matt.xyz++ short that he uses it, and it also runs on a Teensy with steppers. I set my pins and DH parameters, and the forward kinematics even checked out (the tool sat exactly at X = 175.9 mm), but **moving along X didn't work**.

## 5. Building my own: measuring the kinematics

I knew roughly how IK works and that it needs the robot's geometry, so I measured every axis-to-axis distance and angle in **Fusion 360** (see [03-kinematics.md](03-kinematics.md)). From these measurements the **DH table** was built, and it showed the arm has a **spherical wrist** (J4, J5, J6 axes meet at one point), which is what makes solving the IK practical.

## 6. Building my own app with an AI partner

So I decided to **make my own app**. A full 6-DOF arm was honestly beyond my scope (most people start inverse kinematics with 2 links), and I only wanted one thing first: **move straight in X, Y and Z**. I don't write code at this level yet, so I built it with **Claude (Anthropic)** as a coding partner, asking for every step so the control stayed in my hands. My part was defining what the robot needed, giving it my measurements, pin maps and drive ratios, testing every version on the real robot, and reporting exactly what went wrong. Its part was writing the firmware, IK and app.

The software went through many versions. Each feature below exists because of a real problem:

| Problem on the real robot | What was added |
|---|---|
| Needed to see what the arm *should* do vs what it *does* | Live 3D model: solid = commanded, faint = real motor position |
| Motors didn't move, or moved only a few steps | Hardware **test** buttons, visible serial log, jog speeds in steps/s |
| Angles were 6× wrong, homing stopped halfway | Real **gear ratios** from my drive table (e.g. J2 = 5.18:1 planetary × 80T/16T belt) |
| J3 homed away from its switch | Per-joint **homing direction** button, saved on the Teensy |
| Moving +X made the tool dive down | J3's motor turned opposite to the model → per-joint **motor reverse** |
| Wrist spun 180° when moving down | The IK found a "flipped" wrist solution → **wrist-flip blocking** and **position-only** mode |
| J5 moved ¼ as far as shown | Its driver was on a different microstep setting → **steps/degree** editable and saved |
| Limits stopped the arm too early | **Zero here**, **min/max here**, **endstop only** limits |
| J2 grinding | Too fast for its small motor → per-joint **speed caps**; also found a wiring fault |
| Tool pushed into the table | **Table-height limit** for Cartesian and drawing moves |
| Wanted to draw | **G-code runner**, reachable-area finder, **image/SVG → G-code** |

## 7. First drawings

With calibration done (directions, zeros, steps/degree), the arm follows straight lines in Cartesian space and draws SVG outlines cleanly.

> 📷 Put the first drawing photo and a video link here.

## What I learned

- Making the **real robot match the math** is harder than the math: signs, zero offsets and ratios all have to agree.
- **Open-loop steppers** need careful speeds and good wiring; a stall silently loses position.
- **Test in small steps** and watch the serial log.

## What's next

See [roadmap.md](roadmap.md): deriving and coding the IK myself, and moving the arm to ROS 2 + MoveIt.

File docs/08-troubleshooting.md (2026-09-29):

# Troubleshooting (problems I actually hit)

| Symptom | Cause | Fix |
|---|---|---|
| App connects but nothing moves | Old sketch on the Teensy, or motors disabled | Flash the right firmware; press **Enable all** |
| Jog seems to do nothing | Gear ratio was 1, so a 1° nudge was 4 steps | Set real gear ratios / steps per degree |
| Angle jumps after releasing jog | Display froze while the joint was still decelerating | App follows the real position while coasting |
| Homing stops halfway | Search distance used wrong steps/degree | Correct steps/degree |
| Joint homes away from its switch | Wrong homing direction | **toward** button in the homing card |
| +X makes the tool dive | J3 motor turns opposite to the model | Reverse J3 in **Motor direction** |
| Wrist spins 180° going down | IK switched to the flipped wrist solution at J5's limit | Wrist-flip blocking, **Position only** mode |
| "J5 reached its limit" too early | Wrong steps/degree put the switch in the wrong place | Fix steps/degree, **endstop only** |
| Joint moves ~¼ or ½ of what the app shows | Driver on a different microstep setting | **fix from measurement** |
| Moves blocked after pressing STOP | STOP latch wasn't cleared by Enable | Fixed: enabling clears it; app now warns |
| J2 grinds | Too fast for a 0.4 A motor / tangled wiring | Speed cap (12°/s), check wiring and belt |
| Tool presses into the table | Cartesian moves could go below the surface | **Lowest flange height** limit |

General rule: after any grinding or stall, **re-home** (open-loop steppers lose position silently).

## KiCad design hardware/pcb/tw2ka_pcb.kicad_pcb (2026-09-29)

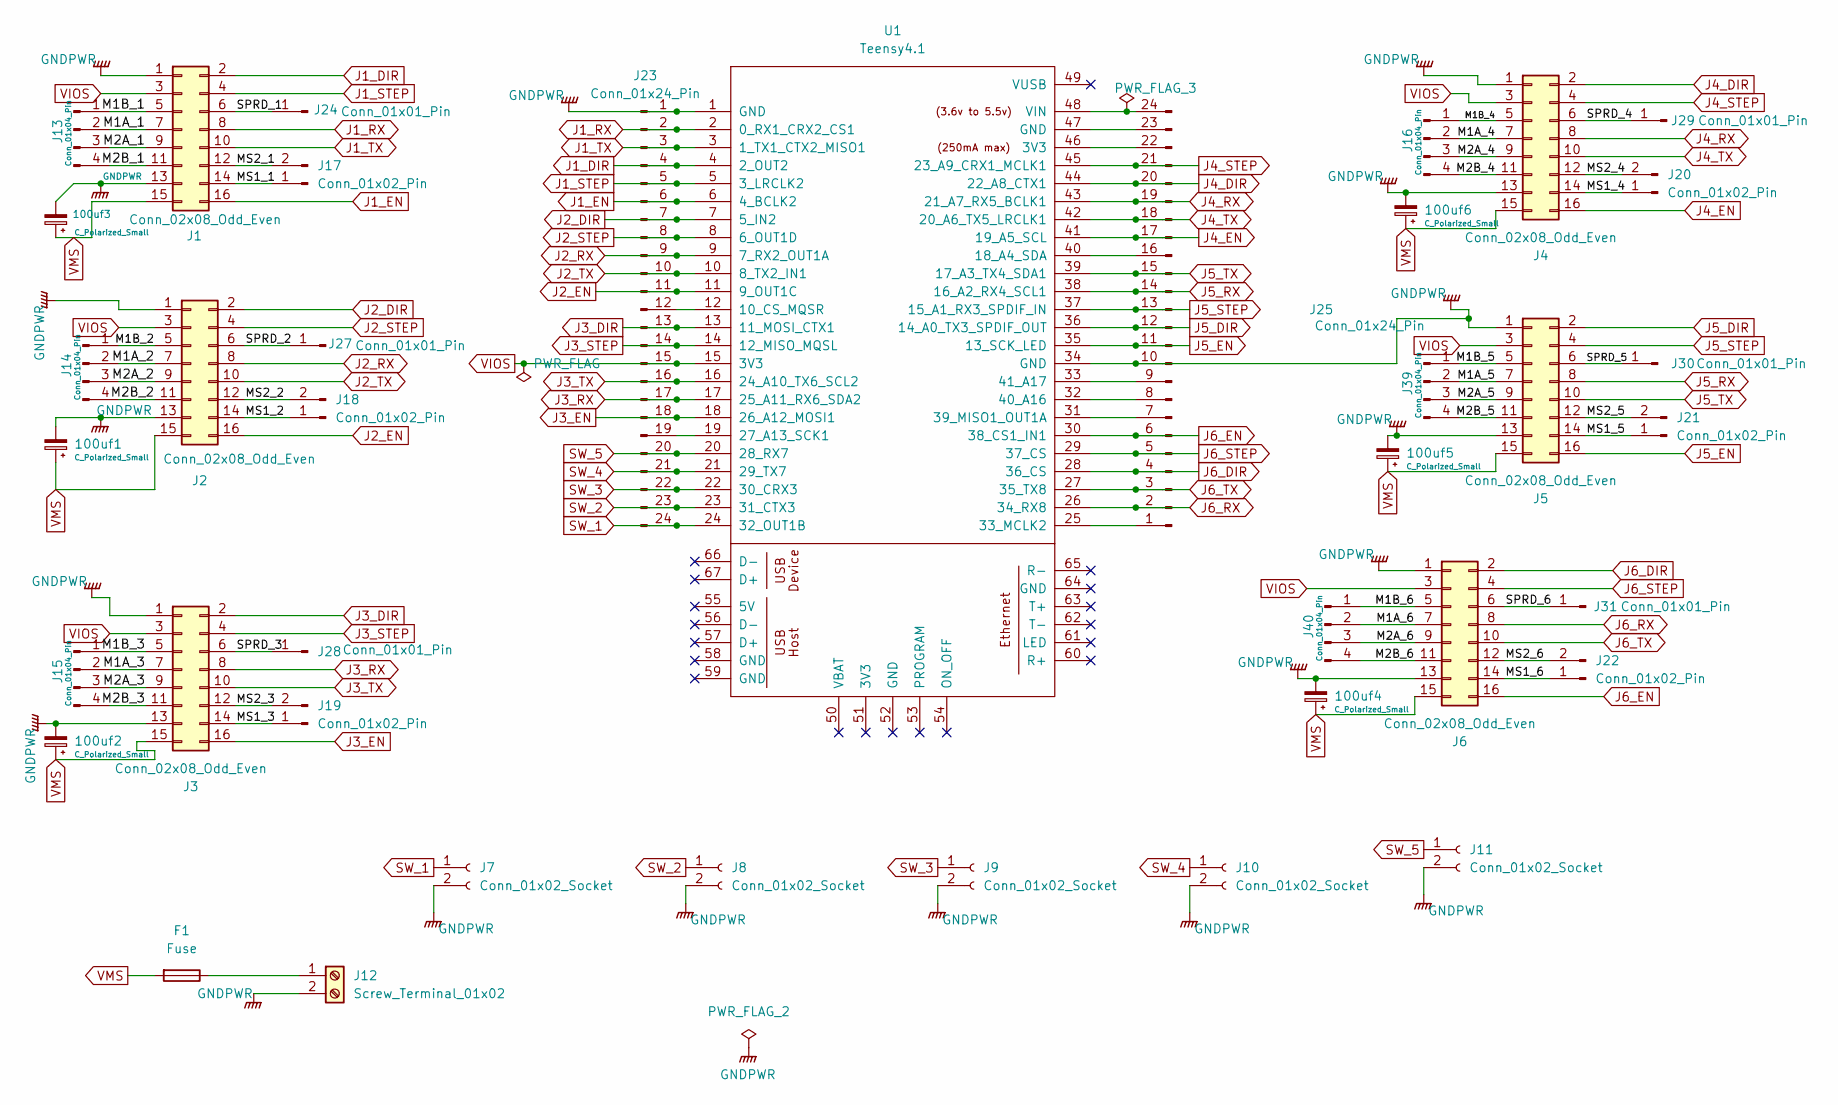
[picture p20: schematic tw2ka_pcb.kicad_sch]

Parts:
100uf1, 100uf2, 100uf3, 100uf4, 100uf5, 100uf6: C_Polarized_Small; CP_Elec_6.3x7.7
F1: Fuse; Fuseholder_Cylinder-5x20mm_Schurter_0031_8201_Horizontal_Op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
J1, J2, J3, J4, J5, J6: Conn_02x08_Odd_Even; TMC2209_MODULE
J7, J8, J9, J10, J11: Conn_01x02_Socket; PinHeader_1x02_P2.54mm_Vertical
J12: Screw_Terminal_01x02; TerminalBlock_Phoenix_MKDS-1,5-2-5.08_1x02_P5.08mm_Horizont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
J13, J14, J15, J16, J39, J40: Conn_01x04_Pin; PinHeader_1x04_P2.54mm_Vertical
J17, J18, J19, J20, J21, J22: Conn_01x02_Pin; PinHeader_1x02_P2.54mm_Vertical
J23, J25: Conn_01x24_Pin; PinHeader_1x24_P2.54mm_Vertical
J24, J27, J28, J29, J30, J31: Conn_01x01_Pin; PinHeader_1x01_P2.54mm_Vertical
U1: Teensy4.1; Teensy41

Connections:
/M1A_1: J1.7, J13.2
/M1A_2: J2.7, J14.2
/M1A_3: J3.7, J15.2
/M1A_4: J4.7, J16.2
/M1A_5: J5.7, J39.2
/M1A_6: J6.7, J40.2
/M1B_1: J1.5, J13.1
/M1B_2: J2.5, J14.1
/M1B_3: J3.5, J15.1
/M1B_4: J4.5, J16.1
/M1B_5: J5.5, J39.1
/M1B_6: J6.5, J40.1
/M2A_1: J1.9, J13.3
/M2A_2: J2.9, J14.3
/M2A_3: J3.9, J15.3
/M2A_4: J4.9, J16.3
/M2A_5: J5.9, J39.3
/M2A_6: J6.9, J40.3
/M2B_1: J1.11, J13.4
/M2B_2: J2.11, J14.4
/M2B_3: J3.11, J15.4
/M2B_4: J4.11, J16.4
/M2B_5: J5.11, J39.4
/M2B_6: J6.11, J40.4
/MS1_1: J1.14, J17.1
/MS1_2: J2.14, J18.1
/MS1_3: J3.14, J19.1
/MS1_4: J4.14, J20.1
/MS1_5: J5.14, J21.1
/MS1_6: J6.14, J22.1
/MS2_1: J1.12, J17.2
/MS2_2: J2.12, J18.2
/MS2_3: J3.12, J19.2
/MS2_4: J4.12, J20.2
/MS2_5: J5.12, J21.2
/MS2_6: J6.12, J22.2
/SPRD_1: J1.6, J24.1 (Pin_1_1)
/SPRD_2: J2.6, J27.1 (Pin_1_1)
/SPRD_3: J3.6, J28.1 (Pin_1_1)
/SPRD_4: J4.6, J29.1 (Pin_1_1)
/SPRD_5: J5.6, J30.1 (Pin_1_1)
/SPRD_6: J6.6, J31.1 (Pin_1_1)
GNDPWR: 100uf1.2, 100uf2.2, 100uf3.2, 100uf4.2, 100uf5.2, 100uf6.2, J1.1, J1.13, J2.1, J2.13, J3.1, J3.13, J4.1, J4.13, J5.1, J5.13, J6.1, J6.13, J7.2, J8.2, J9.2, J10.2, J11.2, J12.2, J23.1, J25.10, U1.1 (GND), U1.34 (GND)
J1_DIR: J1.2, J23.4, U1.4 (2_OUT2)
J1_EN: J1.16, J23.6, U1.6 (4_BCLK2)
J1_RX: J1.8, J23.2, U1.2 (0_RX1_CRX2_CS1)
J1_STEP: J1.4, J23.5, U1.5 (3_LRCLK2)
J1_TX: J1.10, J23.3, U1.3 (1_TX1_CTX2_MISO1)
J2_DIR: J2.2, J23.7, U1.7 (5_IN2)
J2_EN: J2.16, J23.11, U1.11 (9_OUT1C)
J2_RX: J2.8, J23.9, U1.9 (7_RX2_OUT1A)
J2_STEP: J2.4, J23.8, U1.8 (6_OUT1D)
J2_TX: J2.10, J23.10, U1.10 (8_TX2_IN1)
J3_DIR: J3.2, J23.13, U1.13 (11_MOSI_CTX1)
J3_EN: J3.16, J23.18, U1.18 (26_A12_MOSI1)
J3_RX: J3.8, J23.17, U1.17 (25_A11_RX6_SDA2)
J3_STEP: J3.4, J23.14, U1.14 (12_MISO_MQSL)
J3_TX: J3.10, J23.16, U1.16 (24_A10_TX6_SCL2)
J4_DIR: J4.2, J25.20, U1.44 (22_A8_CTX1)
J4_EN: J4.16, J25.17, U1.41 (19_A5_SCL)
J4_RX: J4.8, J25.19, U1.43 (21_A7_RX5_BCLK1)
J4_STEP: J4.4, J25.21, U1.45 (23_A9_CRX1_MCLK1)
J4_TX: J4.10, J25.18, U1.42 (20_A6_TX5_LRCLK1)
J5_DIR: J5.2, J25.12, U1.36 (14_A0_TX3_SPDIF_OUT)
J5_EN: J5.16, J25.11, U1.35 (13_SCK_LED)
J5_RX: J5.8, J25.14, U1.38 (16_A2_RX4_SCL1)
J5_STEP: J5.4, J25.13, U1.37 (15_A1_RX3_SPDIF_IN)
J5_TX: J5.10, J25.15, U1.39 (17_A3_TX4_SDA1)
J6_DIR: J6.2, J25.4, U1.28 (36_CS)
J6_EN: J6.16, J25.6, U1.30 (38_CS1_IN1)
J6_RX: J6.8, J25.2, U1.26 (34_RX8)
J6_STEP: J6.4, J25.5, U1.29 (37_CS)
J6_TX: J6.10, J25.3, U1.27 (35_TX8)
unnamed: F1.1, J12.1
unnamed: J23.12, U1.12 (10_CS_MQSR)
unnamed: J23.19, U1.19 (27_A13_SCK1)
unnamed: J25.1, U1.25 (33_MCLK2)
unnamed: J25.7, U1.31 (39_MISO1_OUT1A)
unnamed: J25.8, U1.32 (40_A16)
unnamed: J25.9, U1.33 (41_A17)
unnamed: J25.16, U1.40 (18_A4_SDA)
unnamed: J25.22, U1.46 (3V3)
unnamed: J25.23, U1.47 (GND)
unnamed: J25.24, U1.48 (VIN)
SW_1: J7.1, J23.24, U1.24 (32_OUT1B)
SW_2: J8.1, J23.23, U1.23 (31_CTX3)
SW_3: J9.1, J23.22, U1.22 (30_CRX3)
SW_4: J10.1, J23.21, U1.21 (29_TX7)
SW_5: J11.1, J23.20, U1.20 (28_RX7)
VIOS: J1.3, J2.3, J3.3, J4.3, J5.3, J6.3, J23.15, U1.15 (3V3)
VMS: 100uf1.1, 100uf2.1, 100uf3.1, 100uf4.1, 100uf5.1, 100uf6.1, F1.2, J1.15, J2.15, J3.15, J4.15, J5.15, J6.15

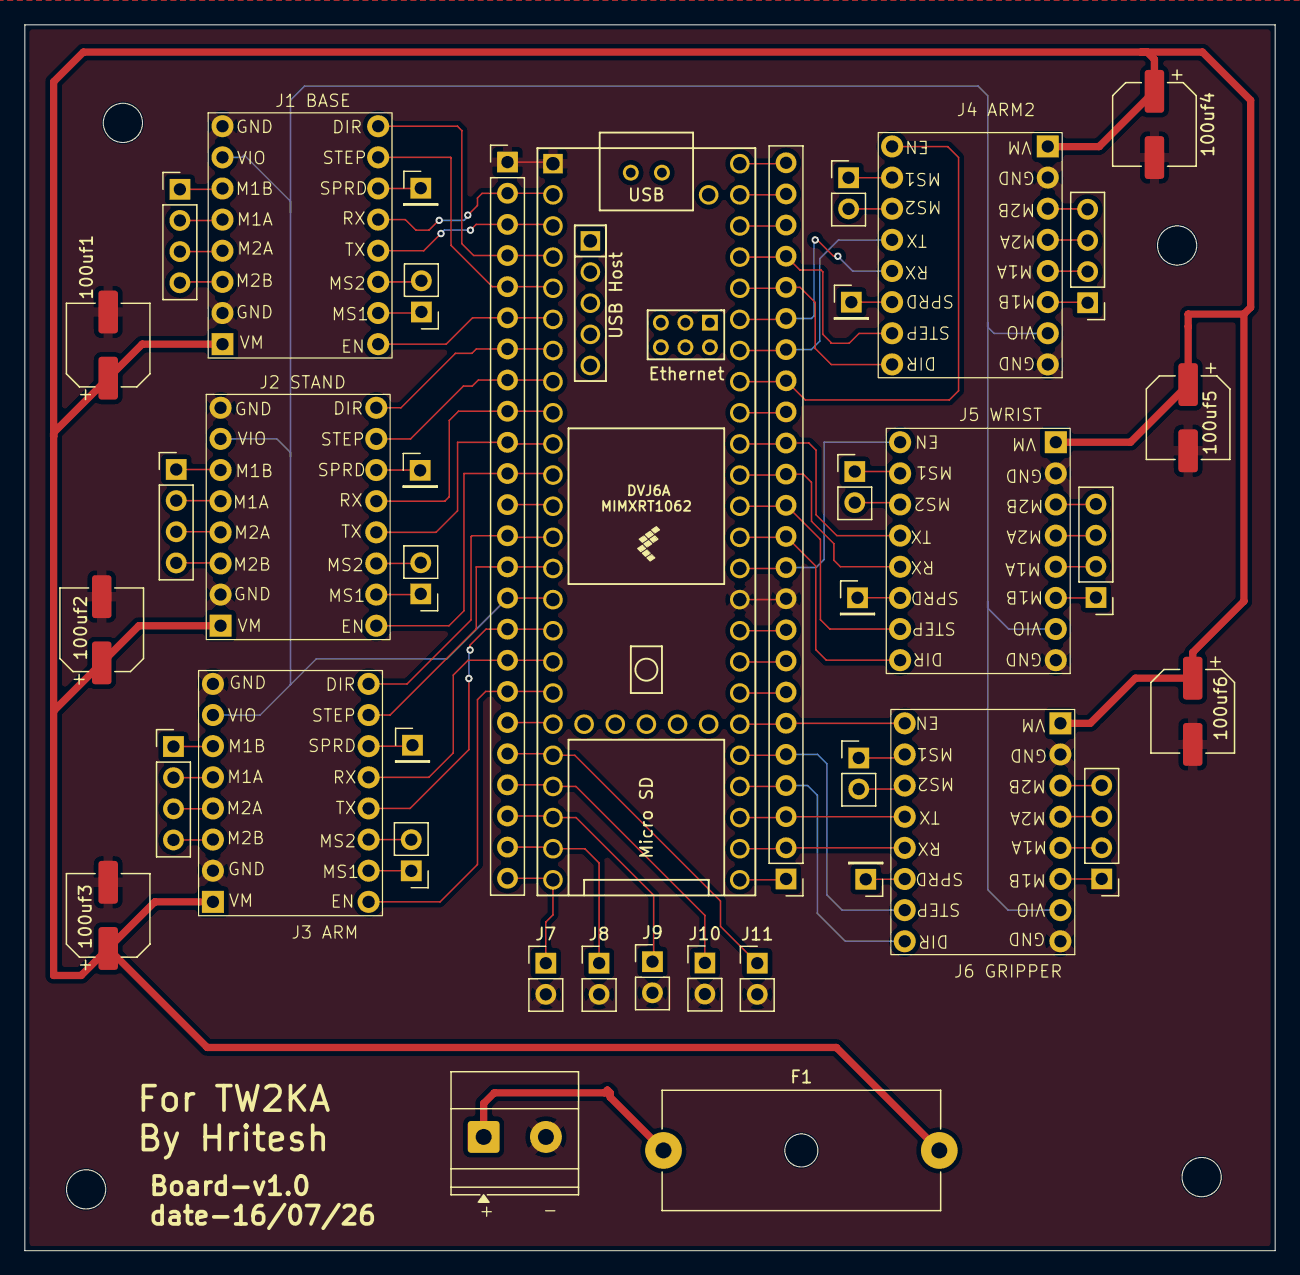
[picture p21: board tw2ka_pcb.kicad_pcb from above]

Board: 4 copper layers, 102.0 x 100.0 mm, 40 parts (0 on the bottom side), 91 nets.

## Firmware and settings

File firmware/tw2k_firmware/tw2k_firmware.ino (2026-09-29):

// TW2KA 6-axis arm firmware — Teensy 4.1 + 6x TMC2209 (STEP/DIR) + 5 NC endstops
// Library: AccelStepper by Mike McCauley (Arduino Library Manager)
//
// Serial protocol (USB, one command per line):
//   M j1 j2 j3 j4 j5 j6   move to joint angles in degrees (absolute, coordinated)
//   V deg_per_s           set max joint speed
//   H                     home J1–J5 using the endstops, then go to the zero pose
//   H n                   home only joint n (1–5)
//   Z                     declare the current position as zero on all axes (no homing)
//   S                     smooth stop (decelerate)
//   E                     emergency stop: halt instantly and disable all drivers
//   R                     re-enable all drivers
//   N n 1 / N n 0         enable / disable joint n only (1–6)
//   J n +1 / J n -1       start jogging joint n (hold-to-jog, like the old GUI)
//   J 0 0                 stop jogging
//   D n +1 / D n -1       set which way joint n drives to find its switch (saved in EEPROM)
//   I n 1 / I n 0         reverse / normal motor direction for joint n (saved in EEPROM)
//   O n                   make joint n's current position its new 0 (saved; applied after every homing)
//   K n min max           set joint n's soft limits in degrees (saved)
//   G n spd               set joint n's steps per degree (saved), e.g. G 5 35.556
//   X                     forget saved directions, zeros and limits (then power-cycle)
//   T n                   hardware test: bit-bang 1600 steps forward and back on joint n
//   ?                     report position, switches and status
// Replies:
//   P j1..j6              joint positions (deg)
//   L s1..s5              endstop states, 1 = pressed
//   N e1..e6              driver enable states, 1 = enabled
//   D d1..d5              homing directions (+1/-1)
//   LIM a1 b1 ... a6 b6   soft limits in degrees
//   INV i1..i6            motor direction, 1 = reversed
//   SPD s1..s6            steps per degree in use
//   OK ..., ERR ..., HOMED

#include <AccelStepper.h>
#include <EEPROM.h>

// ============================ PINS (your board) ============================
const int N = 6;
const uint8_t STEP_PIN[N] = { 3,  6, 12, 23, 15, 37};
const uint8_t DIR_PIN[N]  = { 2,  5, 11, 22, 14, 36};
const uint8_t EN_PIN[N]   = { 4,  9, 26, 19, 13, 38};   // active LOW
const int8_t  SW_PIN[N]   = {32, 31, 30, 29, 28, -1};   // J6: no switch fitted (pin 27 reserved)
// Endstops: NC contact to signal, COM to GND, INPUT_PULLUP.
// Not pressed = LOW. Pressed = HIGH. A broken wire also reads HIGH, which fails safe.

// ======================= MECHANICS: CHECK EVERY LINE =======================
const float MOTOR_STEPS = 200.0;          // 1.8° motors
const float MICROSTEPS  = 8.0;            // TMC2209 standalone with MS1=MS2=GND
// Reductions from your drive table. Steps/deg = 200 x 8 x GEAR / 360:
//   J1 27.778, J2 115.111, J3 27.778, J4 16.667, J5 8.889, J6 8.889
float GEAR[N]     = {6.25, 25.9, 6.25, 3.75, 2.0, 2.0};   // J2 = 5.18:1 planetary x 80T/16T belt
bool  INVERT[N]   = {0, 1, 0, 0, 0, 0};   // J2 inverted so '+' matches the old Data_receive sketch
// Soft limits (deg). J1–J3 converted from the old sketch's J*minSteps/J*maxSteps.
// J4–J6 were placeholders in the old sketch too: measure real travel and update. Keep in sync with the app's LIMITS.
float LIM_MIN[N]  = {-144, -13, -54, -180, -20, -180};
float LIM_MAX[N]  = { 144,  87,  68,   10, 120,  180};
float speedDeg    = 30.0;                 // deg/s (app overrides)
float accelDeg    = 90.0;                 // deg/s^2
// Top speed per joint (deg/s), whatever speed the app asks for. J2 has the weakest
// motor (0.4 A) behind a 25.9:1 reduction, so it stalls and grinds if driven fast.
float MAX_DEG_S[N] = {45, 12, 40, 60, 90, 90};
// Jog speeds in STEPS per second, copied from the old Data_receive sketch so jogging
// looks the same even before the gear ratios above are filled in.
float JOG_DEG[N]  = {30, 10, 25, 40, 60, 60};        // jog speed, deg/s
float JOG_ACC_DEG[N] = {120, 40, 100, 160, 240, 240}; // jog ramp, deg/s^2 (stops within ~2-4 deg)

// ================================ HOMING ==================================
// Directions and back-off distances copied from the old Data_receive homing:
//   J1 seeks DIR LOW, J2 DIR HIGH (inverted joint), J3 LOW, J4 HIGH, J5 LOW
int8_t HOME_DIR[N]  = {-1, -1, -1, 1, -1, 0};
// Old sketch backed off J*calibrationReturn steps from the switch and called that 0.
// Using the same numbers puts 0 exactly where your old GUI had it.
const long OLD_RETURN_STEPS[N] = {4300, 1650, 1620, 200, 200, 0};
float  HOME_POS[N];                       // angle at the switch, computed in calcHome()
float  HOME_OFF[N] = {0, 0, 0, 0, 0, 0};  // your zero correction from "Set zero here" (saved)
const uint8_t HOME_ORDER[] = {4, 3, 2, 1, 0};   // J5, J4, J3, J2, J1 (wrist first, keeps it tucked)
float HOME_FAST[N] = {9, 4, 9, 20, 30, 0};   // search speed deg/s (old sketch's calibration speeds)
float HOME_SLOW[N] = {2, 1, 2, 5, 8, 0};     // precise second touch
float backoffDeg  = 5.0;                  // retreat after first touch
float SEARCH_MAX[N] = {360, 120, 150, 360, 200, 0}; // give up if no switch within this travel (deg)
// Before homing, jogging is allowed but soft limits are OFF (angles are relative to power-up).
// Endstops still stop the arm. Home before using Cartesian/IK moves.
bool warnedUnhomed = false;
// ==========================================================================

AccelStepper *m[N];
float spd[N];              // steps per degree
bool enabled = true, ready = false, aborted = false;
bool homedJ[N] = {0, 0, 0, 0, 0, 1};              // J6 has no switch   // enabled = at least one driver on
bool jEn[N] = {1, 1, 1, 1, 1, 1};                      // per-joint enable
bool swState[N], swRaw[N]; uint32_t swSince[N];
String rx;

// ------------------------------- helpers ---------------------------------
void reportEnable() {
  Serial.print("N");
  for (int i = 0; i < N; i++) { Serial.print(' '); Serial.print(jEn[i] ? 1 : 0); }
  Serial.println();
}
void setJoint(int i, bool on) {
  if (!on) m[i]->setCurrentPosition(m[i]->currentPosition());   // stop this joint first
  jEn[i] = on;
  digitalWrite(EN_PIN[i], on ? LOW : HIGH);
  enabled = false; for (int k = 0; k < N; k++) enabled |= jEn[k];
}
void setEnable(bool on) { for (int i = 0; i < N; i++) setJoint(i, on); reportEnable(); }

void report() {
  Serial.print("P");
  for (int i = 0; i < N; i++) { Serial.print(' '); Serial.print(m[i]->currentPosition() / spd[i], 2); }
  Serial.println();
}
void reportHomeDir() {
  Serial.print("D");
  for (int i = 0; i < 5; i++) { Serial.print(' '); Serial.print((int)HOME_DIR[i]); }
  Serial.println();
  Serial.print("INV");
  for (int i = 0; i < N; i++) { Serial.print(' '); Serial.print(INVERT[i] ? 1 : 0); }
  Serial.println();
  Serial.print("SPD");
  for (int i = 0; i < N; i++) { Serial.print(' '); Serial.print(spd[i], 3); }
  Serial.println();
  Serial.print("LIM");
  for (int i = 0; i < N; i++) { Serial.print(' '); Serial.print(LIM_MIN[i], 1); Serial.print(' '); Serial.print(LIM_MAX[i], 1); }
  Serial.println();
}

// Flip which way a joint seeks its switch. The soft limits were written for the
// original direction, so mirror them too (the switch moves to the other end).
// EEPROM layout: [0] magic, [1..5] HOME_DIR+1, [6..11] INVERT
const uint8_t EE_MAGIC = 0xB8, EE_MAGIC_OLD = 0xB7;   // 0xB7 = older firmware (directions only)
// [15] second magic, [16..] zeros and limits you set from the app
const uint8_t EE_CAL_MAGIC = 0xC2, EE_CAL_MAGIC_OLD = 0xC1;   // C1 = older block without steps/deg
struct Cal { float lmin[N], lmax[N], off[N], spd[N]; };
void saveEE() {
  EEPROM.write(0, EE_MAGIC);
  for (int k = 0; k < 5; k++) EEPROM.write(1 + k, (uint8_t)(HOME_DIR[k] + 1));
  for (int k = 0; k < N; k++) EEPROM.write(6 + k, INVERT[k] ? 1 : 0);
  Cal c; for (int k = 0; k < N; k++) { c.lmin[k] = LIM_MIN[k]; c.lmax[k] = LIM_MAX[k]; c.off[k] = HOME_OFF[k]; c.spd[k] = spd[k]; }
  EEPROM.put(16, c); EEPROM.write(15, EE_CAL_MAGIC);
}
bool okNum(float x) { return x == x && fabs(x) < 10000; }   // rejects NaN and blank EEPROM
void calcHome(int i) { HOME_POS[i] = HOME_DIR[i] * OLD_RETURN_STEPS[i] / spd[i] + HOME_OFF[i]; }
void mirrorLimits(int i) { float a = LIM_MIN[i], b = LIM_MAX[i]; LIM_MIN[i] = -b; LIM_MAX[i] = -a; }
void setHomeDir(int i, int d, bool save) {
  if (d == HOME_DIR[i]) return;
  mirrorLimits(i);
  HOME_DIR[i] = d;
  HOME_OFF[i] = 0;                         // other switch side: old zero correction no longer applies
  calcHome(i);
  if (save) saveEE();
}
// Reverse a motor so its '+' matches the 3D model. The arm doesn't move: its angle
// just changes sign, and homing still drives the same physical way (toward the switch).
void setInvert(int i, bool inv, bool save) {
  if (inv == INVERT[i]) return;
  INVERT[i] = inv;
  m[i]->setPinsInverted(inv, false, false);
  m[i]->setCurrentPosition(-m[i]->currentPosition());
  mirrorLimits(i);
  HOME_DIR[i] = -HOME_DIR[i];
  HOME_OFF[i] = -HOME_OFF[i];
  calcHome(i);
  if (save) saveEE();
}

void reportSwitches() {
  Serial.print("L");
  for (int i = 0; i < N; i++) if (SW_PIN[i] >= 0) { Serial.print(' '); Serial.print(swState[i] ? 1 : 0); }
  Serial.println();
}

// 2 ms debounce; returns true if any switch changed
bool updateSwitches() {
  bool changed = false; uint32_t now = micros();
  for (int i = 0; i < N; i++) {
    if (SW_PIN[i] < 0) continue;
    bool r = digitalRead(SW_PIN[i]) == HIGH;
    if (r != swRaw[i]) { swRaw[i] = r; swSince[i] = now; }
    else if (r != swState[i] && now - swSince[i] > 2000) { swState[i] = r; changed = true; }
  }
  return changed;
}

void haltAll() { for (int i = 0; i < N; i++) m[i]->setCurrentPosition(m[i]->currentPosition()); }

// Read serial without blocking; returns true when a full line is in `out`
bool readLine(String &out) {
  while (Serial.available()) {
    char c = Serial.read();
    if (c == '\n') { out = rx; rx = ""; out.trim(); return true; }
    if (c != '\r' && rx.length() < 120) rx += c;
  }
  return false;
}

// Called inside blocking homing loops: only E and S are accepted
bool checkAbort() {
  String s;
  if (readLine(s) && s.length()) {
    if (s[0] == 'E') { haltAll(); setEnable(false); Serial.println("OK E-STOP drivers disabled"); aborted = true; }
    else if (s[0] == 'S') { haltAll(); Serial.println("OK homing cancelled"); aborted = true; }
    else Serial.println("ERR busy homing");
  }
  return aborted;
}

// Split "M 1 2 3" style arguments without sscanf (float sscanf is unreliable on some cores)
int parseArgs(const String &s, float *out, int maxN) {
  int n = 0, i = 1, L = s.length();
  while (n < maxN) {
    while (i < L && s[i] == ' ') i++;
    if (i >= L) break;
    int j = i; while (j < L && s[j] != ' ') j++;
    out[n++] = s.substring(i, j).toFloat();
    i = j;
  }
  return n;
}

// ------------------------------- motion ----------------------------------
void moveJoints(float *tgt) {
  float dDeg[N], maxD = 0;
  for (int i = 0; i < N; i++) {
    if (!jEn[i]) tgt[i] = m[i]->currentPosition() / spd[i];   // disabled joint: hold its count, send no steps
    if (ready) tgt[i] = constrain(tgt[i], LIM_MIN[i], LIM_MAX[i]);   // soft limits only mean something after homing
    dDeg[i] = fabs(tgt[i] - m[i]->currentPosition() / spd[i]);
    maxD = max(maxD, dDeg[i]);
  }
  if (maxD < 0.001) return;
  float T = 0;                                 // move time set by the slowest-allowed joint
  for (int i = 0; i < N; i++) T = max(T, dDeg[i] / min(speedDeg, MAX_DEG_S[i]));
  for (int i = 0; i < N; i++) {               // all joints finish together
    float v = max(dDeg[i] / T, 0.02f * maxD / T);   // this joint's cruise speed, deg/s
    float f = v * T / maxD;                    // share of the move, for a matching ramp
    m[i]->setMaxSpeed(v * spd[i]);
    m[i]->setAcceleration(accelDeg * f * spd[i]);
    m[i]->moveTo(lround(tgt[i] * spd[i]));
  }
}

// Constant-speed jog on one joint until the switch reaches `wantPressed`
bool jogUntil(int i, int dir, float degPerSec, bool wantPressed, float maxDeg) {
  long start = m[i]->currentPosition(), maxSteps = lround(maxDeg * spd[i]);
  m[i]->setMaxSpeed(degPerSec * spd[i] * 1.1);
  m[i]->setSpeed(dir * degPerSec * spd[i]);
  uint32_t t = millis();
  while (true) {
    updateSwitches();
    if (swState[i] == wantPressed) return true;
    if (labs(m[i]->currentPosition() - start) > maxSteps) return false;
    m[i]->runSpeed();
    if (millis() - t > 100) { t = millis(); report(); reportSwitches(); if (checkAbort()) return false; }
  }
}

bool homeAxis(int i) {
  if (!jEn[i]) { Serial.print("ERR J"); Serial.print(i + 1); Serial.println(" is disabled"); return false; }
  if (SW_PIN[i] < 0 || HOME_DIR[i] == 0) { Serial.print("ERR J"); Serial.print(i + 1); Serial.println(" has no endstop"); return false; }
  Serial.print("OK homing J"); Serial.println(i + 1);
  int d = HOME_DIR[i];
  if (swState[i] && !jogUntil(i, -d, HOME_FAST[i], false, 30)) goto fail;          // start off the switch
  if (!jogUntil(i, d, HOME_FAST[i], true, SEARCH_MAX[i])) goto fail;                // fast search
  if (!jogUntil(i, -d, HOME_FAST[i], false, 30)) goto fail;                        // release
  { long p = m[i]->currentPosition() - d * lround(backoffDeg * spd[i]);           // back off a bit more
    m[i]->setMaxSpeed(HOME_FAST[i] * spd[i]); m[i]->setAcceleration(accelDeg * spd[i]); m[i]->moveTo(p);
    while (m[i]->distanceToGo()) { m[i]->run(); if (checkAbort()) goto fail; } }
  if (!jogUntil(i, d, HOME_SLOW[i], true, backoffDeg * 3)) goto fail;              // slow precise touch
  m[i]->setCurrentPosition(lround(HOME_POS[i] * spd[i]));
  homedJ[i] = true;
  delay(5); updateSwitches(); delay(3); updateSwitches(); reportSwitches();   // show the pressed switch in the app
  return true;
fail:
  if (!aborted) { Serial.print("ERR J"); Serial.print(i + 1); Serial.println(" switch not found"); }
  return false;
}

void homeAll(int only) {
  if (!enabled) { Serial.println("ERR disabled, send R"); return; }
  aborted = false; haltAll();
  bool ok = true;
  if (only >= 0) ok = homeAxis(only);
  else for (uint8_t k = 0; k < sizeof(HOME_ORDER) && ok; k++) ok = homeAxis(HOME_ORDER[k]);
  if (!ok) { Serial.println("ERR homing failed"); report(); return; }
  if (only < 0) {                                  // J6 has no switch: its power-up position counts as 0
    ready = true;
    float zero[N] = {0, 0, 0, 0, 0, 0}; moveJoints(zero);
    Serial.println("HOMED");
  } else {
    Serial.print("OK J"); Serial.print(only + 1); Serial.println(" homed");
    bool all = true; for (int k = 0; k < N; k++) all &= homedJ[k];
    if (all && !ready) { ready = true; Serial.println("OK homed"); }
  }
  report();
}
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
void loop() {
  String s;
  if (readLine(s)) handle(s);

  if (updateSwitches()) reportSwitches();

  bool moving = false;
  for (int i = 0; i < N; i++) {
    // Endstop hit while driving toward it: stop everything immediately
    if (SW_PIN[i] >= 0 && swState[i] && m[i]->distanceToGo() * HOME_DIR[i] > 0) {
      haltAll();
      Serial.print("ERR limit J"); Serial.println(i + 1);
      report();
    }
    m[i]->run();
    if (m[i]->distanceToGo() != 0) moving = true;
  }
  if ((moving && sinceReport > 100) || (wasMoving && !moving)) { report(); sinceReport = 0; }
  wasMoving = moving;
}

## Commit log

2026-09-29 Add video link for robot arm demonstration
    Added a link to a video demonstrating the robot arm's drawing capabilities.
2026-09-29 These are the files by Tw2ka youtuber
    [Arm 2.3.STL, Arm 4.3.STL, Arm1v2.STL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]
2026-09-29 Revise README for TW2KA robot arm files
    Updated README to provide detailed information about the TW2KA robot arm files, including credits, contents, usage, and modifications.
2026-09-29 Add Readme for TW2KA Arm Controller web app
    Added comprehensive documentation for the TW2KA Arm Controller web app, including requirements, quick start instructions, features, and additional resources.
2026-09-29 Update README with Teensy connection correction
    Correct the tx and rx connection description for the Teensy board.
